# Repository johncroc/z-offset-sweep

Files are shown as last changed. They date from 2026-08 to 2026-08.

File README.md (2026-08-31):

# Z-Offset Sweep

Print nine first-layer test patches in a single job, each at a **different Z
offset**, with its offset **engraved on the part**.

Instead of babystepping by hand and trying to remember what you set, the offset
is applied automatically per object, mid-print, from the sliced G-code. The
number on the part is the number the printer used — they come from one source
and cannot disagree.

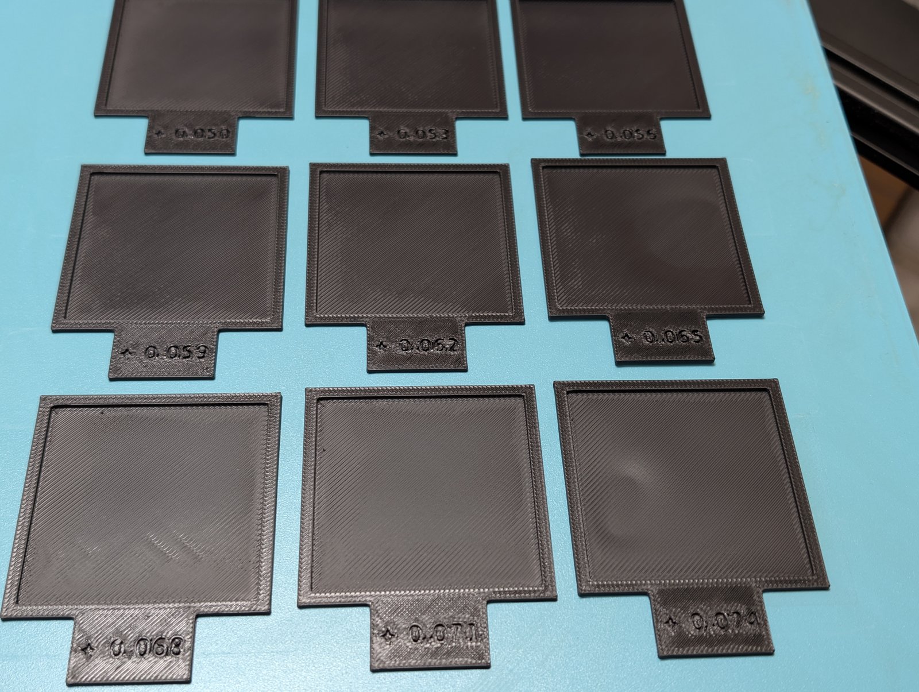
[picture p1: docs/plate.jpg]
Nine printed frames in a 3×3 grid, each engraved with the Z offset it was printed at, running from +0.050 at the back to +0.074 at the front


*A finished sweep, +0.050 (back left) to +0.074 (front right) in 0.003 steps.
The gradient is visible without reading a single label: the back row's
extrusion lines have merged into a solid glossy surface, while by the front row
the individual lines are separated by visible gaps.*

## A real result

On an Elegoo Centauri Carbon with a load-cell probe, running OpenCentauri
COSMOS (Kalico), immediately after a full calibration:

- A coarse read suggested +0.040 was close but slightly tight.
- One 9-frame sweep, **+0.074 → +0.050 in 0.003 steps**, resolved it to
  **+0.056** — the first frame where the lines had fully merged without the
  surface starting to look over-pressed.
- Total cost: one 50-minute unattended print.

0.003 mm steps proved fine enough to distinguish adjacent frames by eye on this
machine, and 0.024 mm of total span was enough to cross the transition. Those
are reasonable starting numbers if you already know roughly where you are; open
the span up and coarsen the step if you don't.

### Two machines, two answers

The same procedure was then run on a second, identical Centauri Carbon —
different COSMOS release, freshly calibrated:

| machine | Z offset found | `position_endstop` |
|---|---|---|
| printer A | **+0.056** | 6.140 |
| printer B | **+0.030** | 4.496 |

Both needed the nozzle **raised** from calibrated zero, so the direction
replicated. The magnitude did not: they differ by 0.026 mm, roughly nine steps
of a fine sweep, on machines whose raw endstop positions differ by 1.6 mm.

Take that as a prior for choosing where to sweep — start on the positive side of
zero — and not as a number to copy. A value borrowed from another machine, even
the same model on the same firmware, is a guess wearing three decimal places.

## Why

The usual way to find a Z offset is to start a print, watch the first layer,
nudge the offset live, and remember which nudge produced the good result. That
works, but the record lives in your head. If you print a labelled test plate
instead, the label is only a *claim* about what the printer did — one mistimed
babystep and you have a physical object that lies to you, permanently.

This removes the gap. The offset is encoded in each object's filename. The
slicer carries that name into the G-code as an object marker. A post-processing
script reads the value back out of that marker and emits the matching
`SET_GCODE_OFFSET`. The engraving and the applied offset are the same number,
derived from the same place.

## How it works

```
FreeCAD Params sheet          z_start / z_end / n_frames
        │
        ├─ engraves the value on the tab   (ShapeString → pocket)
        └─ writes it into the filename     Z-Offset-Test-04-pos-0.065.stl
                   │
                   ▼
             slicer emits            EXCLUDE_OBJECT_START NAME=...pos-0.065...
                   │
                   ▼
        post-processing script inserts
              SET_GCODE_OFFSET Z=0.065 MOVE=1 MOVE_SPEED=5
```

Because the slicer re-emits object markers on every layer, the offset
re-asserts itself per frame per layer. It is self-correcting: a missed
injection is fixed by the next one.

## Requirements

- **Klipper or Kalico.** `SET_GCODE_OFFSET` with `Z_ADJUST`/`MOVE` is a core
  `gcode_move` command. Marlin's `M290` is *not* equivalent and this will not
  work as-is on Marlin.
- **A slicer that labels objects.** OrcaSlicer, PrusaSlicer and SuperSlicer all
  emit `EXCLUDE_OBJECT_START NAME=`. In Orca the setting is
  *Print Settings → Others → Exclude objects*.
- **FreeCAD 1.1+** if you want to change the range. If the bundled STLs suit
  you, you don't need FreeCAD at all.

Tested on an Elegoo Centauri Carbon running OpenCentauri COSMOS (Kalico), and
on the stock Elegoo firmware, whose C++ Klipper reimplementation also
implements `SET_GCODE_OFFSET` faithfully.

## Use

### 1. Generate the frames (optional)

Open `cad/z-offset-test-tab.FCStd`, set the sweep in the **Params** sheet:

| alias | meaning |
|---|---|
| `z_start` | first offset |
| `z_end` | last offset — may be *below* `z_start` for a descending sweep |
| `n_frames` | how many frames |
| `z_decimals` | decimal places in label and filename |
| `grid_cols` | frames per row |
| `grid_gap` | gap between frames, mm |
| `out_dir` | optional output path; defaults to `stl/` beside the .FCStd |

Run `macro/ZOffsetSweep.FCMacro`. It writes one STL per frame, each already
positioned at its own spot in the grid, and reports the derived step:

```
Z-offset sweep: 9 frames, +0.074 -> +0.050, step 0.003 (descending)
grid: 3 x 3 at 62.0 x 76.5 mm pitch (footprint 180.0 x 223.5 mm)
```

Check that step against what you intended — a wrong `n_frames` silently
produces a different step, and the labels would be perfectly consistent with
the sweep you didn't want.

### 2. Slice

Import all the STLs **as separate objects**, not merged into one. Merging them
gives you a single object with one name, and the post-processor has nothing to
key on.

Each STL carries its own grid position, but be aware that **most slicers
discard it**: OrcaSlicer auto-arranges on import (Preferences → `auto_arrange`)
and will stack or re-pack them regardless. In practice you will probably
separate and arrange them by hand.

Arrange them in **index order** — `01` at back-left, reading left-to-right then
forward. That is what the two-digit filename prefix is for: the files sort into
sweep order, so you can lay them out without cross-referencing values. A sorted
plate lets you see the transition at a glance; a scrambled one means reading
nine labels and sorting them mentally. Either works — the engraving is
authoritative — but only one of them is quick.

Enable **Exclude objects**, and add the post-processor under
*Print Settings → Others → Post-processing Scripts*:

```
/usr/bin/python3 /path/to/zoffset-sweep-postprocess.py;
```

### 3. Verify before printing

```
grep -c zoffset-sweep sliced.gcode      # expect frames × layers, + 1 reset
```

This check matters — see *Silent failure* below.

### 4. Print and read

The whole diagnostic is in **layer 1**. Later layers only build the frame wall
and the tab. Note the engraving is a pocket in the *top* of the tab, so it does
not finish forming until the last layer — cancel early and you get unlabelled
patches.

## Things that will bite you

### `MOVE=1` is mandatory

```gcode
SET_GCODE_OFFSET Z=0.065 MOVE=1 MOVE_SPEED=5
```

Without `MOVE=1`, the command only updates `base_position`. The toolhead does
not physically move until the next command carrying a `Z` word — and mid-layer,
every extrusion move is X/Y/E only. So all frames would print at the same
height and the offsets would first take effect at the *next layer change*.

The result looks like a successful print of correctly labelled frames that all
have identical first layers. `MOVE=1` forces the corrective move at the moment
of injection, during the travel between objects.

### Silent failure: wrong process preset

The post-processing script is attached to a **process/print preset**. If you
change presets — and selecting a filament can drag you onto a different one —
the script is silently not invoked. There is no error, because nothing ran.

You get nine identically-printed frames wearing nine different engraved
numbers: the exact failure this design exists to prevent, slipping in one layer
below where the naming protects you. The script raises loudly if it runs and
finds no matching objects, but it cannot raise if it never runs. Hence the
`grep` check above.

### The offset survives a cancelled print

The reset to `Z=0` is the last line of the file. Cancel mid-print and the last
applied offset stays active, quietly biasing whatever you print next. Klipper's
`CANCEL_PRINT` does not clear `gcode_offset`. After any cancelled sweep:

```gcode
SET_GCODE_OFFSET Z=0 MOVE=0
```

Worth adding to your own `PRINT_END`/`CANCEL_PRINT` override.

### Absolute vs relative

This script emits absolute `Z=`, which overwrites any offset already applied —
including one your start G-code may have set. That is deliberate: it makes each
frame's value mean the same thing regardless of print order. If your firmware
applies a calibrated Z offset as a live `gcode_offset` rather than baking it
into the endstop, use `Z_ADJUST=` instead so the sweep rides on top of it.

## Layout

```
cad/          FreeCAD parametric source
macro/        generator macro (FreeCAD)
postprocess/  slicer post-processing script
stl/          example sweep, +0.074 → +0.050 in 0.003 steps
```

## Licence

Dual-licensed by component:

- **Code** — `macro/`, `postprocess/` — MIT. See `LICENSE-MIT`.
- **Model** — `cad/`, `stl/` — CC BY-SA 4.0. See `LICENSE-CC-BY-SA-4.0`.

© 2026 John Crockett

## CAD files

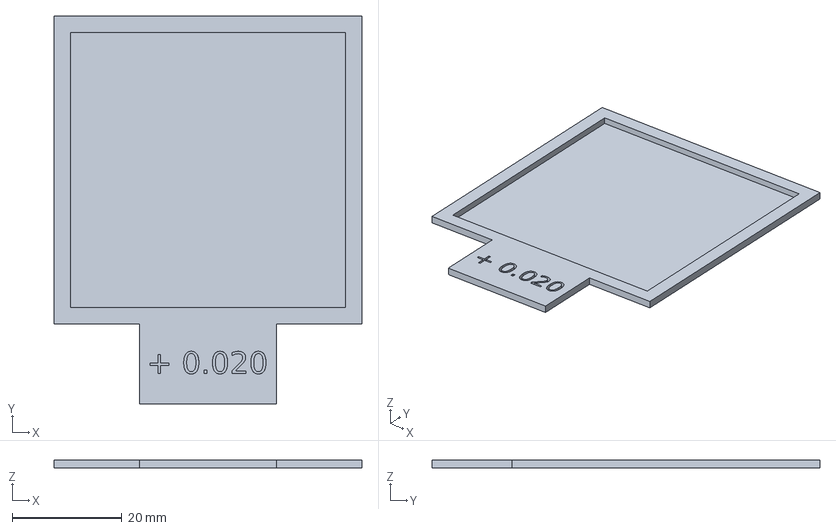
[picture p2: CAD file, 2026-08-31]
cad/z-offset-test-tab.FCStd
56.0 x 70.5 x 1.50 mm

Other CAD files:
stl/Z-Offset-Test-06-pos-0.059.stl
stl/Z-Offset-Test-07-pos-0.056.stl
stl/Z-Offset-Test-08-pos-0.053.stl
stl/Z-Offset-Test-05-pos-0.062.stl
stl/Z-Offset-Test-04-pos-0.065.stl
stl/Z-Offset-Test-03-pos-0.068.stl
stl/Z-Offset-Test-01-pos-0.074.stl
stl/Z-Offset-Test-02-pos-0.071.stl
stl/Z-Offset-Test-09-pos-0.050.stl

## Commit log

2026-08-31 Z-offset sweep: parametric calibration plate with per-object offset injection
    Nine first-layer patches printed in one job, each at its own Z offset, with
    the offset engraved on the part. The value is encoded in the STL filename,
    carried into the G-code as an object marker, and read back by a slicer
    post-processing script that emits the matching SET_GCODE_OFFSET. The engraving
    and the applied offset derive from one number and cannot drift apart.
    Code MIT, model CC BY-SA 4.0.
    [Z-Offset-Test-01-pos-0.074.stl, Z-Offset-Test-02-pos-0.071.stl, Z-Offset-Test-03-pos-0.068.stl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]
2026-08-31 Add finished-plate photo and a real calibration result
    Sweep of +0.074 -> +0.050 in 0.003 steps on an Elegoo Centauri Carbon under
    COSMOS resolved the Z offset to +0.056 in one 50-minute print.
2026-08-31 Correct the slicing step: slicers discard baked STL positions
    The macro places each frame at its own grid spot, but OrcaSlicer auto-arranges
    on import and throws the coordinates away, so frames still need separating and
    arranging by hand. The README claimed they arrive pre-arranged, which is not
    true of any slicer's defaults.
    The two-digit index prefix is what actually helps: files sort into sweep order,
    so arranging by hand needs no cross-referencing.
2026-08-31 Add second-machine result: direction replicates, magnitude does not
    Same procedure on a second Centauri Carbon found +0.030 against the first
    machine's +0.056. Both needed a positive offset from calibrated zero, so the
    direction is a useful prior for choosing a sweep range, but the magnitude is
    machine-specific and not transferable.
